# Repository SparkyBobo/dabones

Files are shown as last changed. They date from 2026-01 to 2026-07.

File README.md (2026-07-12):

# DaBones

DaBones is a Halloween animatronic rock show project combining mechanical characters, embedded electronics, lighting control, audio playback, and stage effects.

The goal is to create a repeatable live Halloween performance experience where animated characters perform as a band with synchronized movement, lighting, and effects.

## Project Status

Current release:

**DaBones v1.0 — Halloween 2026**

The focus of v1.0 is a complete, reliable show experience.

The goal is not to complete every possible feature. Future enhancements are intentionally deferred into later releases.

## System Overview

DaBones consists of several integrated systems:

* Animated characters
* Mechanical motion systems
* Embedded controllers
* Lighting and DMX control
* Audio and MIDI synchronization
* Stage infrastructure
* Special effects

## Engineering Approach

The project follows a release-based engineering model:

* Define the release before building
* Capture design decisions and tradeoffs
* Separate ideas from commitments
* Document why decisions are made
* Build platforms that support future expansion

## Repository Contents

```
docs/
    Release definitions
    Architecture documentation
    Inventory
    Decisions
    Field notes

hardware/
    Electronics designs
    Mechanical designs
    Related hardware files

firmware/
    Embedded software
```

## Relationship to Portfolio

DaBones is one project within a larger personal engineering portfolio.

The portfolio repository contains cross-project planning, engineering practices, and field notes.

## Current Goal

Deliver a complete Halloween 2026 show with a defined minimum viable feature set and a reliable operating experience.

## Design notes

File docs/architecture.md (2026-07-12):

# DaBones System Architecture

## Purpose

This document describes the overall system architecture of DaBones.

It captures the relationships between subsystems and the design intent behind the show platform.

## System Overview

DaBones is an integrated embedded control and performance system.

Major subsystems include:

* Show control
* Character animation
* Lighting
* Audio synchronization
* Mechanical systems
* Stage infrastructure
* Effects

## Show Control

The show requires coordination between:

* Music playback
* Character actions
* Lighting events
* Special effects

The exact implementation will continue to evolve as the system matures.

## Character Systems

Each character consists of:

* Mechanical structure
* Motion mechanisms
* Electronics
* Embedded control
* Lighting elements where appropriate

Characters currently include:

* Joey
* Slash
* Beats
* Tickles
* Lizzy
* Witches

## Lighting System

The lighting system includes:

* DMX-controlled fixtures
* Custom DMX hardware
* Lighting grid/truss structure
* Playback/control software

The lighting platform is largely functional and will be integrated into the v1.0 show.

## Electronics Platform

Character electronics will use reusable controller designs where possible.

Shared hardware and firmware platforms reduce duplication and improve maintainability.

## Audio / MIDI

The show includes audio playback and MIDI-based synchronization.

The MIDI controller system is part of the show control architecture.

## Mechanical Systems

Mechanical design includes:

* Character frames
* Motion mechanisms
* Mounting systems
* Stage structures

Mechanical reliability is a primary release constraint.

## Design Principles

* Prefer reusable platforms
* Capture decisions
* Separate experiments from releases
* Build reliable systems before adding features

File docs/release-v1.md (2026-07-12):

# DaBones v1.0 Release Definition

## Purpose

DaBones v1.0 is the first complete Halloween show release.

The objective is a reliable, entertaining animatronic rock performance that can be presented to an audience.

## Deadline

Halloween 2026

## Release Philosophy

v1.0 prioritizes:

* A complete experience
* Reliability
* Integration
* Audience impact

Features that are interesting but not required for the core experience are deferred.

## Minimum Show

The v1.0 show should include:

* Completed stage environment
* Functional lighting system
* Music playback
* Animated performers
* Synchronized character actions
* Reliable show operation

## Primary Characters

Target v1.0 performers:

* Joey — lead singer
* Slash — guitar player
* Beats — drummer
* Supporting stage elements as schedule allows

## Infrastructure

Required:

* Stage
* Lighting grid/truss
* DMX control
* Power distribution
* Audio system

## Deferred Features

Potential future releases:

* Video system
* Additional characters
* Advanced effects
* Additional choreography
* Expanded automation

## Definition of Done

DaBones v1.0 is complete when:

* The show can run from start to finish
* The audience experience is complete
* Systems are reliable enough for repeated operation
* Remaining ideas can safely move to future releases

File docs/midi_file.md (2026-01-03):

# MIDI Files

## Overview

The DaBones use MIDI format 1 with multiple tracks, one for each "instrument", i.e., character or song element.
A file may contain all song elements or a single element. The file can be transferred to a song element and played
back upon request.

The advantage of using MIDI files is that the song elements can anticipate events from the file, giving
song elements a more natural representation of the event, i.e., the swing of the drum stick appears
more human and less mechanical. Files are used for final playback during a song.

## File Name

DaBones MIDI file names are standardized to provide organized but human readable names making it easy
to load a file and understand what it contains from the file name.

File names start with the unique sequence number for the song followed by an underscore. For example,
song `00 06` would start with "0006_". This makes it easy for the sequence to load the file for a given
song by searching the file list of a song number.

Additionally, files can be transferred between song elements using MIDI system exclusive events. The common
use case is to load the master song file to all elements from a controller. For details regarding file transfers, see [MIDI File Transfers](./midi_file_transfer.md).

## Header

Format 1 header chunk:

Bytes|Value
-----|-----
4D 54 68 64|MThd
00 00 00 06|chunk length
00 01	   |format 1
00 04	   |number tracks
00 60	   |division, 96 ticks per quarter note

### Division

The third word, division, specifies the meaning of the delta-times. It uses ticks per quarter-note:

bit 15|bits 14 thru 0
-----|-----
0|ticks per quarter-note

ticks per quarter-note represent the number of delta time "ticks" which make up a quarter-note.
For instance, if division is 96, then a time interval of an eighth-note between two events in the file would be 48.

## Track 0: Metadata

Track 0 contains the metadata for the file as a track chunk:

Bytes|Value
-----|-----
4D 54 72 6B|MTrk
00 00 xx xx|chunk length

Delta-Time|Event|Comments
-----|-----|-----
00|FF 00 02 xx xx|sequence number
00|FF 03 xx xx xx|sequence name
00|FF 04 04 6d 65 74 61|instrument name, "meta" for track 0
00|FF 20 01 00|MIDI channel prefix, 00000000 for track 0
00|FF 51 03 07 A1 20|tempo
00|FF 2F 00|end of track

### FF 00 02: sequence number

A unique sequence number for the song, e.g., `00 01`

### FF 03 len text: sequence name

The name of the sequence, e.g., 'Skeleton Sam'

### FF 04 len text: instrument name

A description of the type of instrumentation to be used in that track, e.g., "meta" for track 0. Informational only.

### FF 20 01 cc MIDI channel prefix

The MIDI channel for the track, e.g., 00000000 for track 0.

For a list of MIDI channels, see [MIDI Channels](./midi_channel.md)

### FF 51 03 tttttt: tempo

The song tempo in microseconds per MIDI quarter-note, e.g., 07 A1 20 = 500,000 usec/quarter note = 120 beats/minute.

### FF 2F 00 End of Track

This event is not optional. It is included so that an exact ending point may be specified for the track, so that an exact length is defined, which is necessary for tracks which are looped or concatenated.

## Track 1-n: Song element

Tracks 1-n are the different song elements. They are composed of events to trigger each element to correspond to the
sequence being played, e.g., vocal events for a singer:

Bytes|Value
-----|-----
4D 54 72 6B|MTrk
00 00 xx xx|chunk length

Delta-Time|Event|Comments
-----|-----|-----
00|FF 04 04 6d 65 74 61|instrument name, e.g., "joey" or "lights"
00|FF 20 01 cc|MIDI channel prefix.
xx|xx xx xx|MIDI events, i.e., triggers
00|FF 2F 00|end of track

### FF 04 len text: instrument name

A description of the song element for the track, e.g., "joey" or "lights". Informational only.

### FF 20 01 cc MIDI channel prefix

The MIDI channel for the track. This value, not the name, is used to determine which track
applies to which song element.

For a list of MIDI channels, see [MIDI Channels](./midi_channel.md)

### MIDI events

For a list of MIDI events such as notes, controls, and programs, see [MIDI Notes, Controls, and Programs](./midi_notes.md)

### FF 2F 00 End of Track
This event is not optional. It is included so that an exact ending point may be specified for the track, so that an exact length is defined, which is necessary for tracks which are looped or concatenated.

## Example File

The following is a sequence of bytes that represent a song with a male singer and electric guitar playing
at 96 ticks per quarter note, 4/4 time; 24 MIDI clocks/click, 8 32nd notes/24 MIDI clocks, 500,000 usec/quarter note = 120 beats/minute which plays for 4 beats.

Bytes|Value
-----|-----
4D 54 68 64|MThd
00 00 00 06|chunk length
00 01	   |format 1
00 03	   |3 tracks
00 60	   |division, 96 ticks per quarter note
4D 54 72 6B|MTrk, track 0
00 00 00 10|track length (16)
00 FF 00 02 00 00|sequence number, 0.
00 FF 03 74 65 73 74|sequence name, "test"
00 FF 04 04 6d 65 74 61|instrument name, "meta" for track 0
00 FF 20 01 00|MIDI channel prefix, 00 for track 0
00 FF 58 04 04 02 18 08|time signature
00 FF 51 03 07 A1 20|tempo
00 FF 2F 00|end of track
4D 54 72 6B|MTrk, track 1
00 00 00 10|chunk length (16)
00 FF 04 04 6a 6f 65 79|instrument name, "joey"
00 FF 20 01 01|MIDI channel prefix, 00000001 for male singer.
00 C0 05|??
81 40 90 4C 20|??
81 40 4C 00|Running status: note on, vel=0
00 FF 2F 00|end of track
4D 54 72 6B|MTrk, track 2
00 00 00 10|chunk length (16)
00 FF 04 04 73 6c 61 73 68|instrument name, "slash"
00 FF 20 01 06|MIDI channel prefix, 06 for electric guitar.
00 C0 05|??
81 40 90 4C 20|??
81 40 4C 00|Running status: note on, vel=0
00 FF 2F 00|end of track

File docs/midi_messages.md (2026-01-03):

# MIDI Messages

## Overview

The DaBones use MIDI messages, with one MIDI channel for each "instrument", i.e., character or song element.
The messages can be played live as you would play any other instrument to control the song elements.

The disadvantage of using MIDI messages is that song elements cannot anticipate messages, giving them
a less natural representation of the event, i.e., the swing of the drum stick appears
less human and more mechanical. Messages are not used for final playback during a show. Instead,
messages are used to synchronize the show elements during the show.

However, messages are useful during the programming stage. Each song element can respond to the messages
to help show where each song element will be for every moment in the song. While the mechanics may be
unnatural, this is acceptable during programming where it's more important to define the states than
the process of achieving the state.

## Song Playback

When used with MIDI files, MIDI messages can signal start, stop, and timing information for a song.
These messages include:

Status|Data Byte(s)|Description
------|------------|-----------
11110010|0lllllll 0mmmmmmm|Song Position Pointer. This is an internal 14 bit register that holds the number of MIDI beats (1 beat= six MIDI clocks) since the start of the song. l is the LSB, m the MSB.
11110011|0sssssss|Song Select. The Song Select specifies which sequence or song is to be played.
11110110||Tune Request. Upon receiving a Tune Request, all analog synthesisers should tune their oscillators.
11111000||Timing Clock. Sent 24 times per quarter note when synchronisation is required.
11111010||Start. Start the current sequence playing. (This message will be followed with Timing Clocks).
11111011||Continue. Continue at the point the sequence was Stopped.
11111100||Stop. Stop the current sequence.
11111110||Active Sensing. Use of this message is required. When initially sent, the receiver will expect to receive another Active Sensing message each 300ms (max), or it will assume that the connection has been terminated. At termination, the receiver will turn off all voices and return to normal (non-active sensing) operation.
11111111||Reset. Reset all receivers in the system to power-up status.
11110000||System Exclusive. System exclusive messages are used to transfer MIDI files between song elements and select files for playback. For details regarding file transfers, see [MIDI File Transfers](./midi_file_transfer.md).

For details regarding playback, see [MIDI Playback](./midi_playback.md).

## Song Element Control

MIDI messages, with one MIDI channel for each "instrument", i.e., character or song element, the messages can be played live as you would play any other instrument to control the song elements.
Much like a live MIDI stream might be used to control instruments. In this mode, each song element will
respond to its MIDI channel and messages the same as it would during playback, except the element is not
able to anticipate the next event, e.g., the swing of the drum stick appears more mechanical and less human.

Status|Data Byte(s)|Description
------|------------|-----------
1000nnnn|0kkkkkkk 0vvvvvvv|Note Off event. This message is sent when a note is released (ended). (kkkkkkk) is the key (note) number. (vvvvvvv) is the velocity.
1001nnnn|0kkkkkkk 0vvvvvvv|Note On event. This message is sent when a note is depressed (start). (kkkkkkk) is the key (note) number. (vvvvvvv) is the velocity.
1011nnnn|0ccccccc 0vvvvvvv|Control Change. This message is sent when a controller value changes. Controllers include devices such as pedals and levers. Certain controller numbers are reserved for specific purposes. See Channel Mode Messages. (ccccccc) is the controller number. (vvvvvvv) is the new value.
1100nnnn|0ppppppp|Program Change. This message sent when the patch number changes. (ppppppp) is the new program number.
1110nnnn|0lllllll 0mmmmmmm|Pitch Wheel Change. This message is sent to indicate a change in the pitch wheel. The pitch wheel is measured by a fourteen bit value. Centre (no pitch change) is 2000H. Sensitivity is a function of the transmitter. (lllllll) are the least significant 7 bits. (mmmmmmm) are the most significant 7 bits.

For a list of MIDI channels, see [MIDI Channels](./midi_channel.md)
For a list of MIDI notes, controls, and programs, see [MIDI Notes, Controls, and Programs](./midi_notes.md)

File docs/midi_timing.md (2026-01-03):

# MIDI Playback Timing

## Overview

The DaBones use a combination of System Common and System Real-Time messages with MIDI channel 0 for
playback of locally stored MIDI files. The timing related messages and file sections include:

## Messages

Status|Data Byte(s)|Description
------|------------|-----------
11110010|0lllllll 0mmmmmmm|Song Position Pointer. This is an internal 14-bit register that holds the number of MIDI beats (1 beat = six MIDI clocks) since the start of the song. l is the LSB, m the MSB.
11111000||Timing Clock. Sent 24 times per quarter note when synchronisation is required.
11111010||Start. Start the current sequence playing. (This message will be followed with Timing Clocks).

### Song Position Pointer.

This is an internal 14-bit register that holds the number of MIDI beats (1 beat = six MIDI clocks) since the start of the song. l is the LSB, m the MSB: 0lllllll 0mmmmmmm.

The controller may use this message to set the song element sequencers to a fixed point in the song. This register
is reset to 0 when a new song is played.

### Timing Clock

Sent 24 times per quarter note for real-time playback. Can be sent at a slower rate to step through the
events in the MIDI file.

### Start

Start the current sequence playing. (This message will be followed with Timing Clocks). This will reset the song
position register to 0.

## Files

File section|Value|Comment
------------|-----|-----------
Header|division|ticks per quarter-note
Track 0|time signature|time signature
Track 0|tempo|microseconds per MIDI quarter-note

### Division

The division specifies the meaning of the delta-times. It uses ticks per quarter-note:

bit 15|bits 14 thru 0
-----|-----
0|ticks per quarter-note

ticks per quarter-note represent the number of delta time "ticks" which make up a quarter-note.
For instance, if division is 96, then a time interval of an eighth-note between two events in the file would be 48.
If not supplied, the default value is 24.

### Tempo

The song tempo in microseconds per MIDI quarter-note, e.g., 07 A1 20 = 500,000 usec/quarter note = 120 beats/minute.

## Calculations

When playing MIDI files locally, the following process describes how timing is controlled.

1. When a file is loaded, the ticks per quarter note, division, and tempo are set based on the contents of the file header and track metadata. Changes to these parameters are not supported. The position is reset to 0.
2. Determine the ticks per timing clock: ticks per timing clock = division / 24. Default is 1.
3. Calculate the expected timing clock interval: timing clock interval = tempo / 24 milliseconds.
4. Calculate the tick rate: ticks per millisecond = ticks per timing clock / timing clock interval.
5. If no timing clocks are received, play using these calculated variables.
6. If timing clocks are received, use them to override the expected timing and recalculate the tick rate.
7. Recalculate the tick rate using actual timing clock intervals: ticks per millisecond = ticks per timing clock / (current clock time - previous clock time).
8. Increment ticks using the last known tick rate. Timing may be inaccurate if intervals change.
9. Evaluate file events for every tick increment.
10. Increment the song position pointer by 1 every 6 MIDI timing clocks.
11. If the song position pointer is adjusted, calculate ticks = song position pointer * ticks per timing clock * 6 and pause playback.

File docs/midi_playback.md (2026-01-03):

# MIDI Playback

## Overview

The DaBones use a combination of System Common and System Real-Time messages with MIDI channel 0 for
playback of locally stored MIDI files.

For details regarding files, see [MIDI Files](./midi_file.md).
For details regarding file transfers, see [MIDI File Transfers](./midi_file_transfer.md).

## Messages

When used with MIDI files, MIDI messages can signal start, stop, and timing information for a song.
These messages include:

Status|Data Byte(s)|Description
------|------------|-----------
11110010|0lllllll 0mmmmmmm|Song Position Pointer. This is an internal 14-bit register that holds the number of MIDI beats (1 beat = six MIDI clocks) since the start of the song. l is the LSB, m the MSB.
11110011|0sssssss|Song Select. The Song Select specifies which sequence or song is to be played.
11110110||Tune Request. Upon receiving a Tune Request, song elements should "tune" their instruments.
11111000||Timing Clock. Sent 24 times per quarter note when synchronisation is required.
11111010||Start. Start the current sequence playing. (This message will be followed with Timing Clocks).
11111011||Continue. Continue at the point the sequence was Stopped.
11111100||Stop. Stop the current sequence.
11111110||Active Sensing. Use of this message is required. When initially sent, the receiver will expect to receive another Active Sensing message each 300ms (max), or it will be assume that the connection has been terminated. At termination, the receiver will turn off all voices and return to normal (non-active sensing) operation.
11110000|01111111 01111111 00000004 00000001 vvvvvvvv vvvvvvvv|Master volume. Sets the master volume, (vvvvvvvv vvvvvvvv) is the volume level 0-65535, lsb first.
11110000|01111111 01111111 10111111 00000001 ...|Open File
11110000|01111111 01111111 10111111 00000004 ...|Close File
11111111||Reset. Reset all receivers in the system to power-up status.

### Song Position Pointer.

This is an internal 14-bit register that holds the number of MIDI beats (1 beat = six MIDI clocks) since the start of the song. l is the LSB, m the MSB: 0lllllll 0mmmmmmm.

The controller may use this message to set the song element sequencers to a fixed point in the song. This register
is reset to 0 when a new song is played.

### Song Select

The song Select specifies which sequence or song is to be played. It only works for songs 0-127. For higher
song numbers use the system exclusive message Open File for file selection.

### Tune Request

Upon receiving a Tune Request, all song elements "tune" their instruments. This request will trigger the song element
to exercise its functionality in a "power up" sequence to visually show all elements working. The tune request
will last 10 seconds during which the song element will continue to display its pattern.

### Timing Clock

Sent 24 times per quarter note for real-time playback. Can be sent at a slower rate to step through the
events in the MIDI file.

### Start

Start the current song playing. (This message will be followed with Timing Clocks). This will reset the song
position register to 0.

### Continue

Continue at the point the sequence was Stopped. Operates like a pause button on a cassette deck.

### Stop

Stop the current sequence. This will not reset the song position register to 0.

### Active Sensing

Use of this message is required. When initially sent, the receiver will expect to receive another Active Sensing message each 300ms (max), or it will assume that the connection has been terminated. At termination, the receiver will turn off all voices and return to normal (non-active sensing) operation.

### Master Volume

Sets the master volume, (vvvvvvvv vvvvvvvv) is the volume level 0-65535, LSB first. This is a real-time universal system exclusive event and belongs to the playback category.

### Open File

This message specifies the type and location of a MIDI file so it can be loaded. It does not cause the
song to play. This can be used in place of Song Select messages which the song number exceeds 127 or
for specifying a non-standard file name. This is a non-real-time universal system exclusive event and belongs to the playback category.

The command includes the following data bytes:

Data|Comment
----|-------
0ccccccc 0ccccccc|Two 7-bit bytes for command context. Use 00000000 00000000.
0lllllll 0lllllll|Two 7-bit byte combined byte count of type and name, lsb first.
0ttttttt 0ttttttt 0ttttttt 0ttttttt|Four 7-bit bytes for type. Use 'MIDI'.
0nnnnnnn ...|Variable-length, null-terminated, 7-bit ASCII byte file name. Maximum length including terminator is 261 bytes.

If the name specified is a partial match for a single file, that file is opened. For instance, if the
file name is "0006_" and a single file such as "0006_ome_text.mid" exists, it is opened.

### Close File

This message closes an open file and deallocates any memory allocated for the file's contents. This is a non-real-time universal system exclusive event and belongs to the playback category.

The command includes the following data bytes:

Data|Comment
----|-------
0ccccccc 0ccccccc|Two 7-bit bytes for command context. Use 00000000 00000000.

### Reset

Reset all receivers in the system to power-up status. Upon reset, all song elements will perform a "tune" operation
as described in Tune Request.

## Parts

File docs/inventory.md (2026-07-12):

# DaBones Inventory

This document tracks existing hardware, completed work, prototypes, and remaining development.

Status categories:

* Complete
* Functional prototype
* In progress
* Needs design
* Needs build
* Needs integration

---

# Lighting System

Status: Mostly functional

Completed:

* Lighting purchased
* Power wiring built
* DMX wiring built
* DMX circuit built and tested
* Lighting grid/truss operational

Needs:

* Truss reinforcement
* Control software
* Playback software

---

# Slash

Status: Mechanical prototype complete

Completed:

* Guitar mechanics
* Stage mounting
* Skeleton mounting

Needs:

* Circuit build
* Programming
* Costume decoration

---

# Beats

Status: Partial build

Completed:

* Stage
* Partial drum kit
* Parts acquired
* Bass mounted
* High hat mounted
* Initial controller board design exists

Needs:

* Electronics assembly
* Firmware
* Drum mechanism design
* Tom and snare mounting

---

# Tickles

Status: Partial build

Completed:

* Stage
* Keyboard mounted
* Skeleton mounted
* Skulls completed
* Mouth movement working

Needs:

* Playing mechanism
* Spine/skull attachment

---

# Joey

Status: Advanced prototype

Completed:

* Foot tap
* Head movement
* Head mounting
* Body frame
* Hip swing/pelvis mechanism

Needs:

* Body attachment redesign
* Accelerometer integration
* Electronics
* Firmware

---

# Lizzy

Status: Partial build

Completed:

* Head assembly
* Sound
* Mouth movement
* Stage

Needs:

* Body mounting
* Arm mechanism design

---

# Witches

Status: Partial build

Completed:

* Heads prepared
* Mouth mechanisms planned
* Neck motors available

Needs:

* Stage attachment
* Motor installation
* Electronics

---

# Effects

## Smoke

Status: Prototype

Completed:

* Coffee machine prototype
* Fan box
* Fan and tubing

Needs:

* Better enclosure
* Drum riser integration
* Tubing/grille work

## Strobe

Status:
Functional

## Mirror Ball

Status:
Partial

Needs:

* Motor mounting
* Hanging system
* Driver wiring

---

# Marshall Stacks

Status:
Designed / parts available

Completed:

* Design
* Speakers
* Power distribution components
* Control strip components

Needs:

* Construction
* Assembly

---

# Video

Status:
Partial prototype

Completed:

* Approximately half constructed
* Parts available

Needs:

* Testing
* Software

May be deferred from v1.0.

---

# MIDI Controller

Status:
Hardware complete

Needs:

* Programming

---

# Open Questions

* Final v1.0 character lineup
* Final show sequence
* Controller architecture
* Software architecture
* Deferred features

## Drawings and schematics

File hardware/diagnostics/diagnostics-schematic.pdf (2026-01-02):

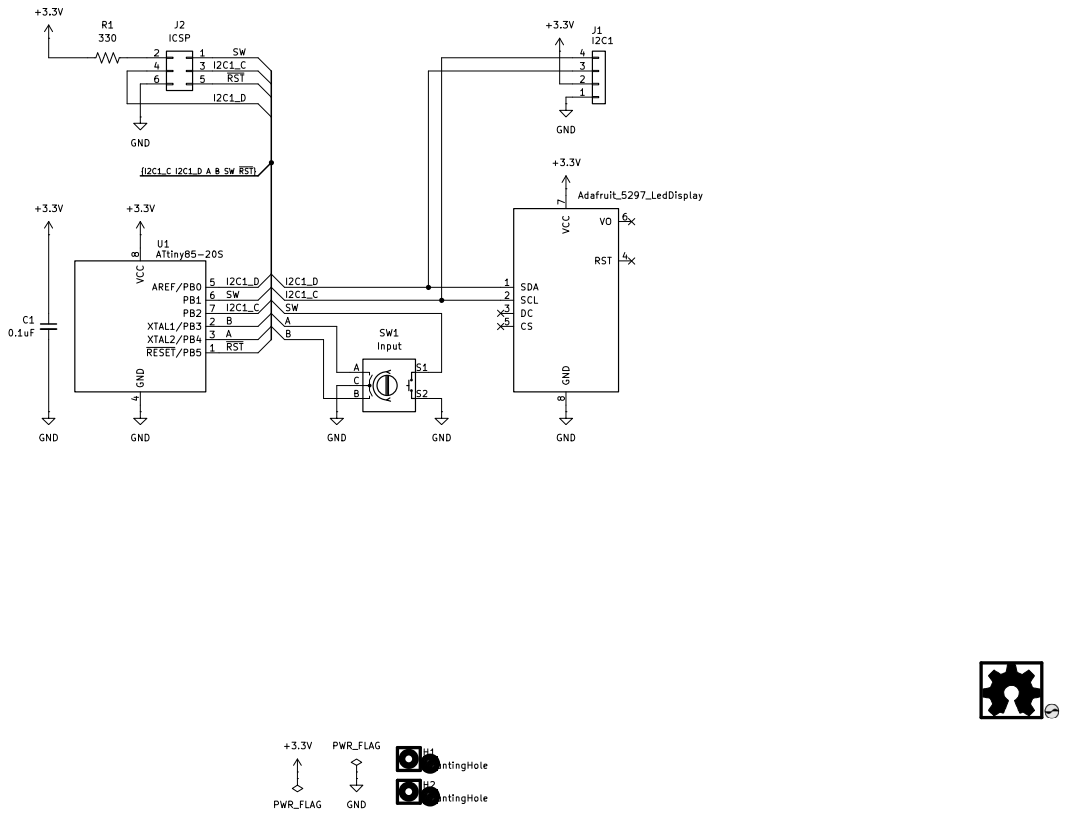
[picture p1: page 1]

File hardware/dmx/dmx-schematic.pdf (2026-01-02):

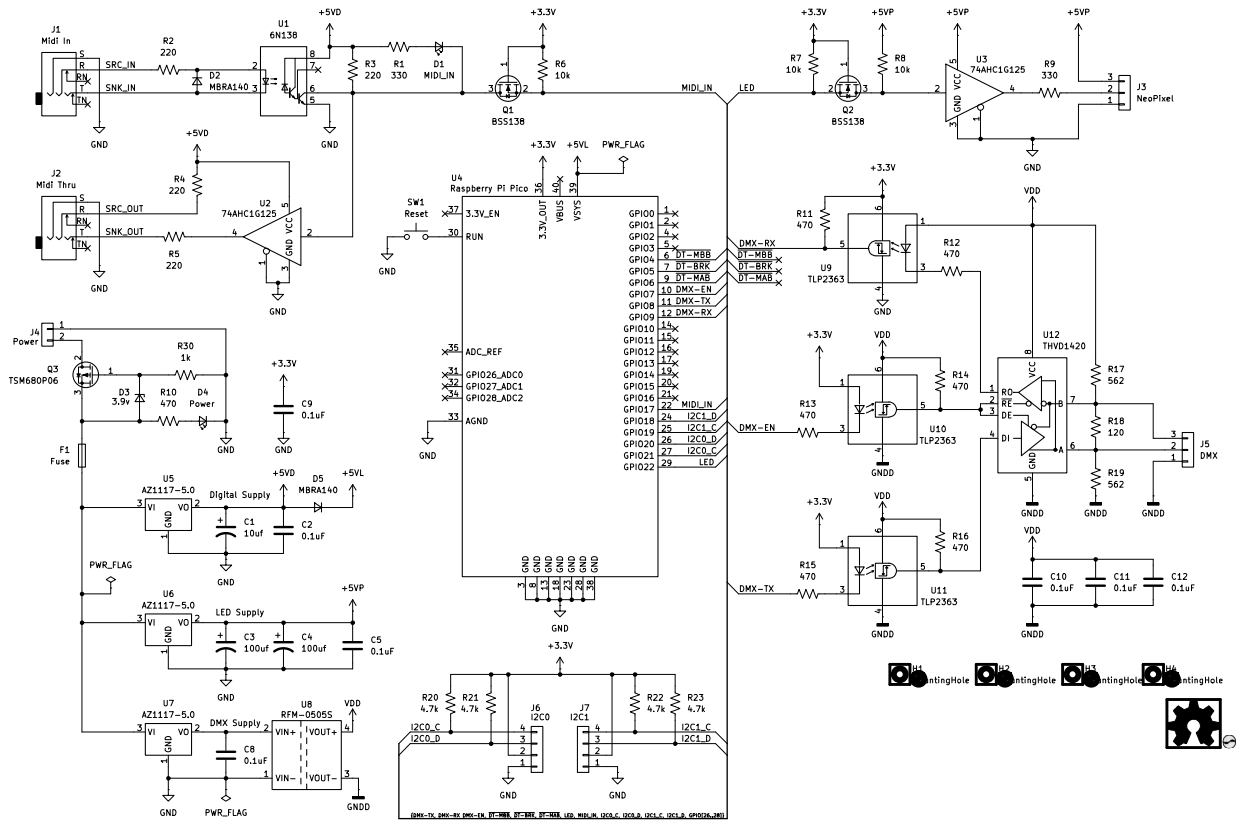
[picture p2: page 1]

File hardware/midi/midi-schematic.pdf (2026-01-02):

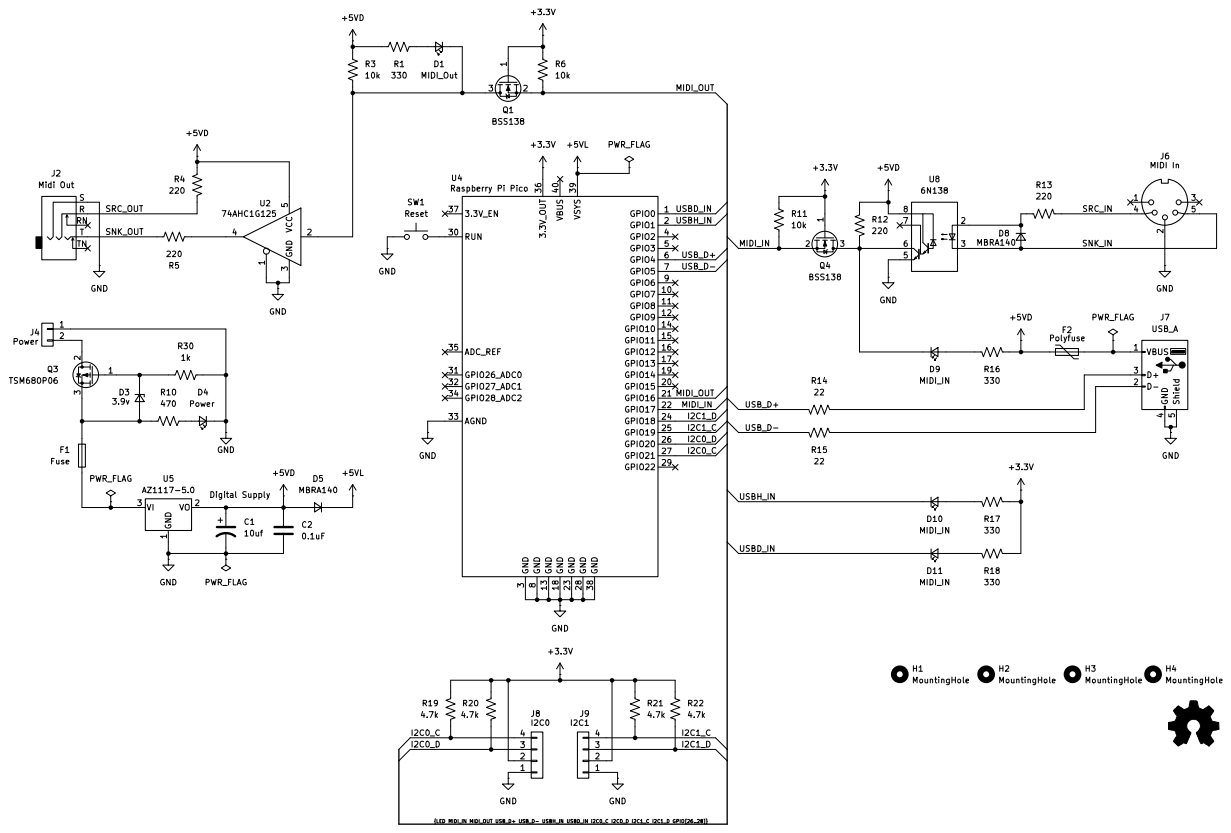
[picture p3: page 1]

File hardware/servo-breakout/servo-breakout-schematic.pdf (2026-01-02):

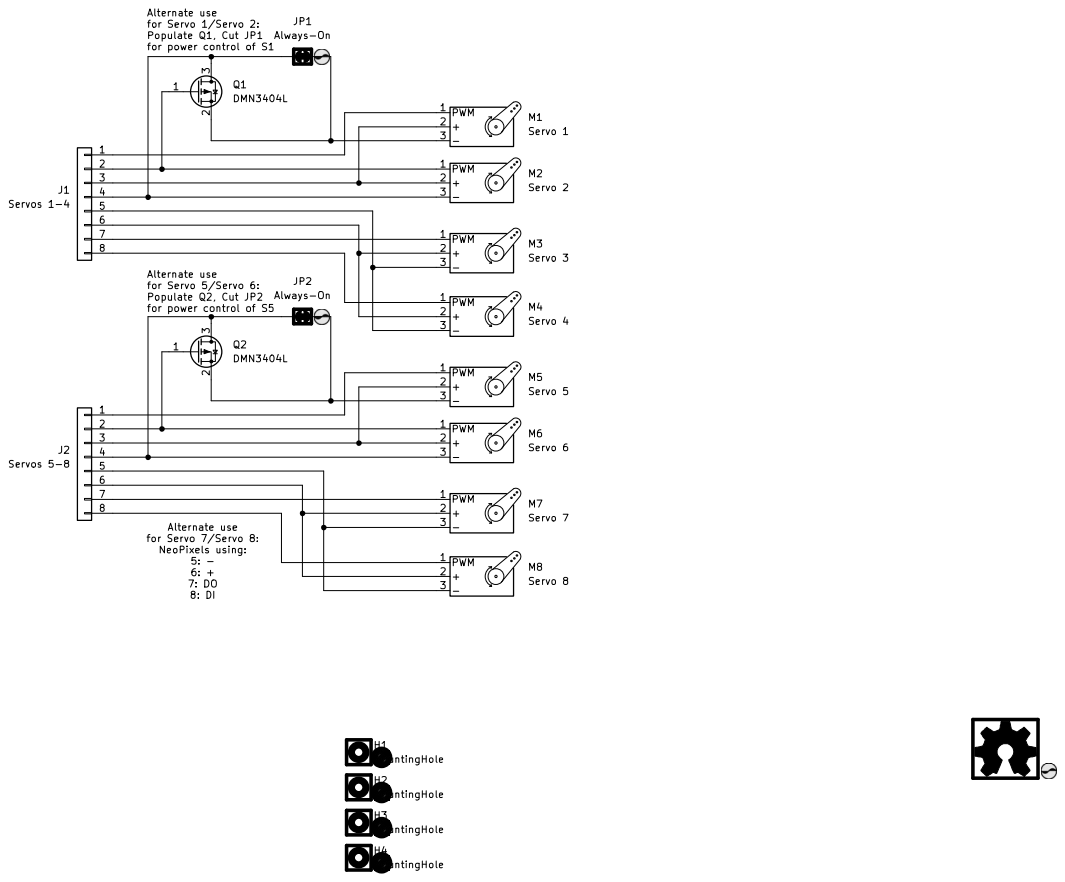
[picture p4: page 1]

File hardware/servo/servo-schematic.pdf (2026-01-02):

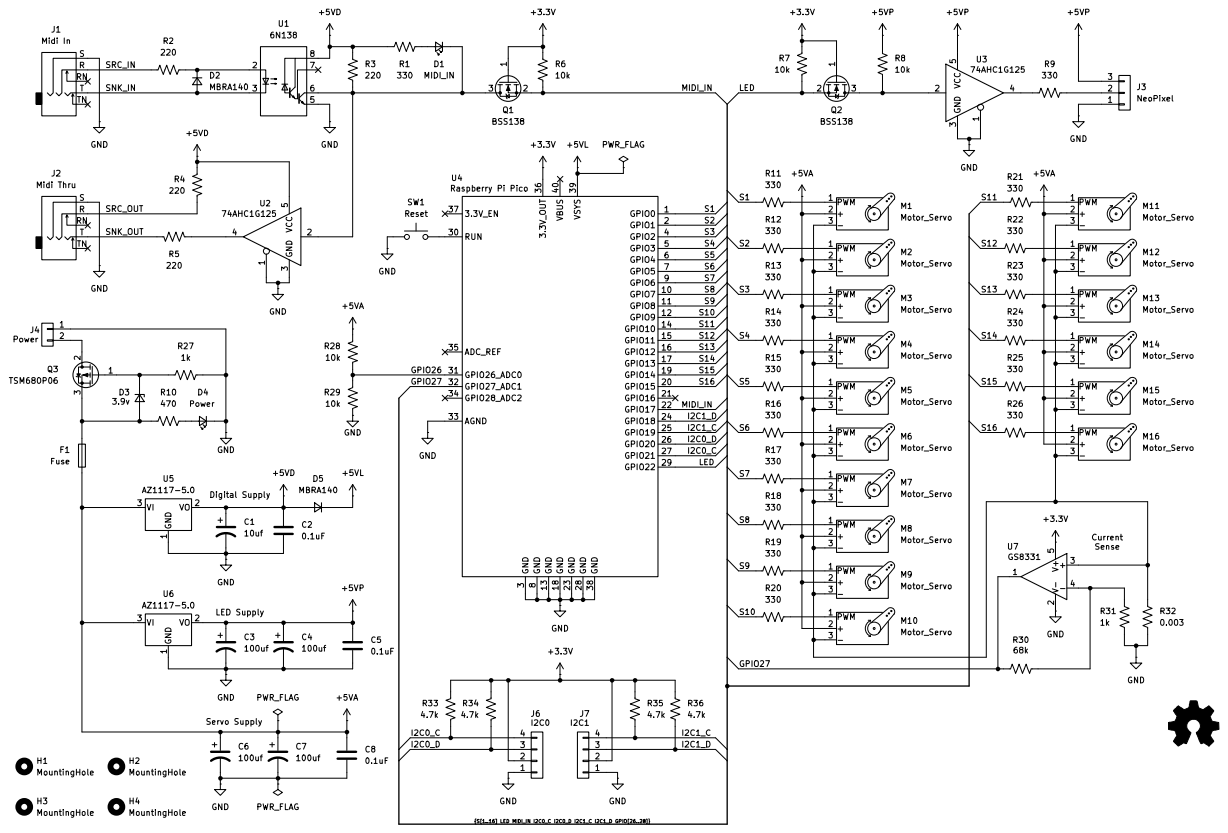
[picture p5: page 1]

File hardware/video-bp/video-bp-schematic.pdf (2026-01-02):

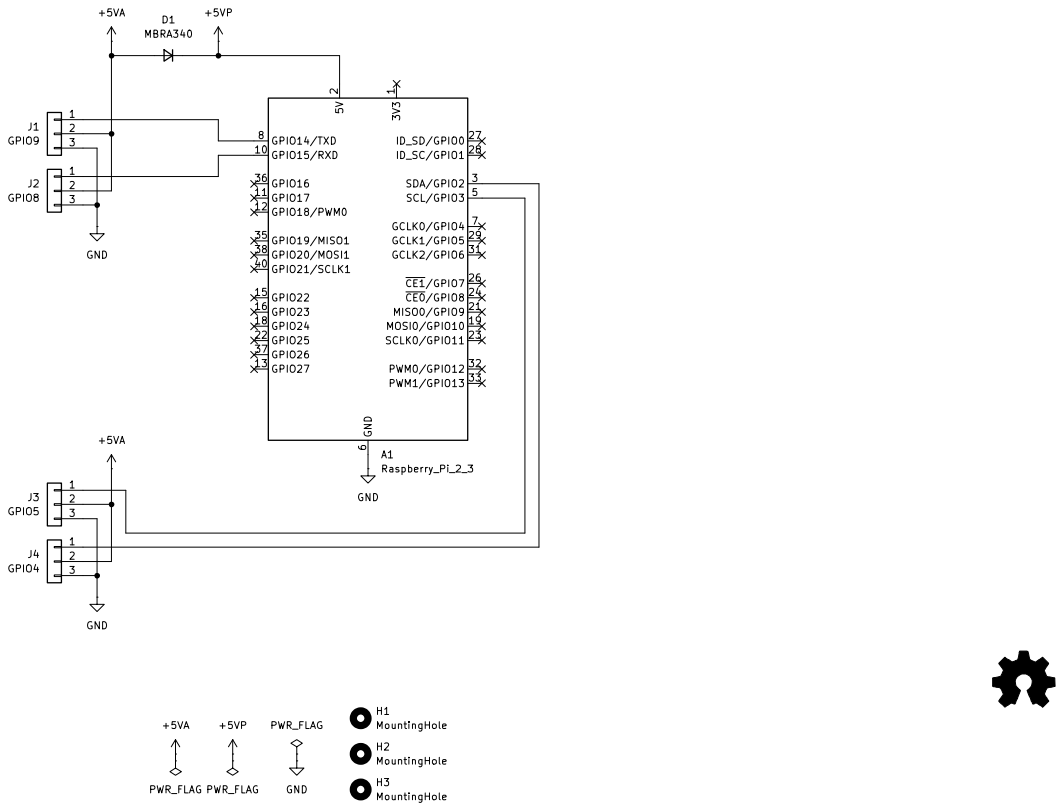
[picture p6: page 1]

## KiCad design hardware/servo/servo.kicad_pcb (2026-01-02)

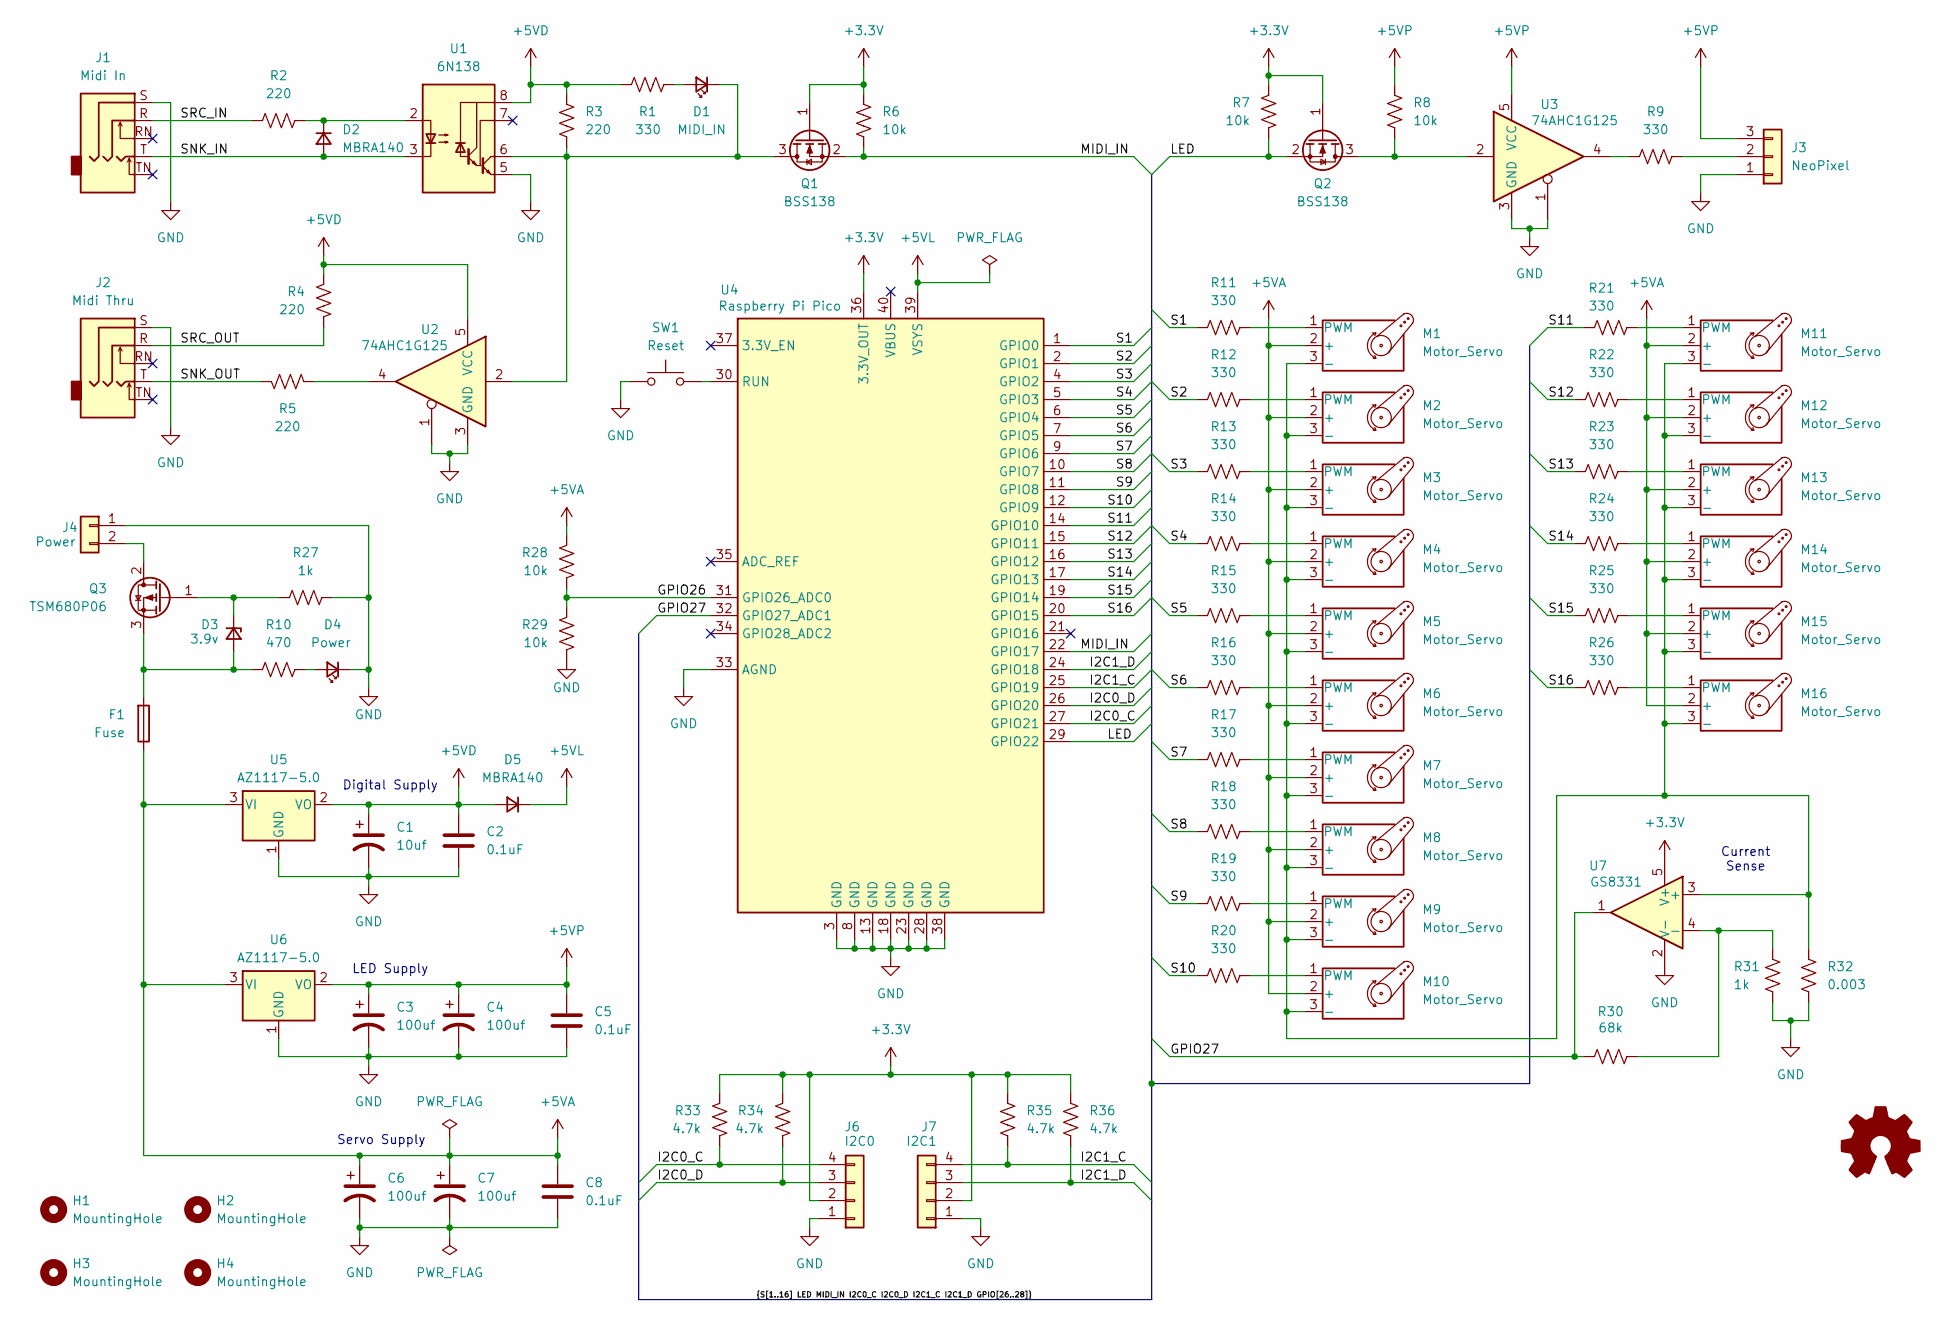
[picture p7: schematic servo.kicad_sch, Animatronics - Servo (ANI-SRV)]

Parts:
C1: 10uf; CP_Radial_D5.0mm_P2.00mm
C2, C5, C8: 0.1uF; C_Rect_L4.0mm_W2.5mm_P2.50mm
C3, C4, C6, C7: 100uf; CP_Radial_D5.0mm_P2.00mm
D1: MIDI_IN; LED_1206_3216Metric_Pad1.42x1.75mm_HandSolder
D2, D5: MBRA140; D_SMA_Handsoldering
D3: 3.9v; D_SOD-123
D4: Power; LED_1206_3216Metric_Pad1.42x1.75mm_HandSolder
F1: Fuse; atc_fuse_vertical
H1, H2, H3, H4: MountingHole; MountingHole_3.2mm_M3
J1: Midi In; Jack_3.5mm_Adafruit_1699_Horizontal
J2: Midi Thru; Jack_3.5mm_Adafruit_1699_Horizontal
J3: NeoPixel; PhoenixContact_MC_1,5_3-G-3.81_1x03_P3.81mm_Horizontal
J4: Power; PhoenixContact_MC_1,5_2-G-3.81_1x02_P3.81mm_Horizontal
J6: I2C0; JST_SH_BM04B-SRSS-TB_1x04-1MP_P1.00mm_Vertical
J7: I2C1; JST_SH_SM04B-SRSS-TB_1x04-1MP_P1.00mm_Horizontal
M1, M2, M3, M4, M5, M6, M7, M8, M9, M10, M11, M12, M13, M14, M15, M16: Motor_Servo; PinHeader_1x03_P2.54mm_Vertical
Q1, Q2: BSS138; SOT-23
Q3: TSM680P06; TO-252-2
R1, R9, R11, R12, R13, R14, R15, R16, R17, R18, R19, R20, R21, R22, R23, R24, R25, R26: 330; R_1206_3216Metric_Pad1.30x1.75mm_HandSolder
R2, R3, R4, R5: 220; R_1206_3216Metric_Pad1.30x1.75mm_HandSolder
R6, R7, R8, R28, R29: 10k; R_1206_3216Metric_Pad1.30x1.75mm_HandSolder
R10: 470; R_1206_3216Metric_Pad1.30x1.75mm_HandSolder
R27, R31: 1k; R_1206_3216Metric_Pad1.30x1.75mm_HandSolder
R30: 68k; R_1206_3216Metric_Pad1.30x1.75mm_HandSolder
R32: 0.003; R_1206_3216Metric_Pad1.30x1.75mm_HandSolder
R33, R34, R35, R36: 4.7k; R_1206_3216Metric_Pad1.30x1.75mm_HandSolder
SW1: Reset; SW_PUSH_6mm
U1: 6N138; SMDIP-8_W9.53mm
U2, U3: 74AHC1G125; SOT-23-5_HandSoldering
U4: Raspberry Pi Pico; RP_Pico_DIP
U5, U6: AZ1117-5.0; SOT-223-3_TabPin2
U7: GS8331; TSOT-23-5

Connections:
+3.3V: J6.2, J7.2, Q1.1 (G), Q2.1 (G), R6.2, R7.2, R33.2, R34.2, R35.2, R36.2, U4.36 (3.3V_OUT), U7.5 (V+)
+5VA: C6.1, C7.1, C8.1, F1.1, M1.2 (+), M2.2 (+), M3.2 (+), M4.2 (+), M5.2 (+), M6.2 (+), M7.2 (+), M8.2 (+), M9.2 (+), M10.2 (+), M11.2 (+), M12.2 (+), M13.2 (+), M14.2 (+), M15.2 (+), M16.2 (+), R28.2, U5.3 (VI), U6.3 (VI)
+5VD: C1.1, C2.1, D5.2 (A), R1.2, R3.1, R4.2, U1.8 (VCC), U2.5 (VCC), U5.2 (VO)
+5VL: D5.1 (K), U4.39 (VSYS)
+5VP: C3.1, C4.1, C5.1, J3.3, R8.2, U3.5 (VCC), U6.2 (VO)
/GPIO26: R28.1, R29.2, U4.31 (GPIO26_ADC0)
/GPIO27: R30.1, U4.32 (GPIO27_ADC1), U7.1
/I2C0_C: J6.4, R33.1, U4.27 (GPIO21)
/I2C0_D: J6.3, R34.1, U4.26 (GPIO20)
/I2C1_C: J7.4, R35.1, U4.25 (GPIO19)
/I2C1_D: J7.3, R36.1, U4.24 (GPIO18)
/LED: Q2.2 (S), R7.1, U4.29 (GPIO22)
/MIDI_IN: Q1.2 (S), R6.1, U4.22 (GPIO17)
/S1: R11.1, U4.1 (GPIO0)
/S2: R12.1, U4.2 (GPIO1)
/S3: R13.1, U4.4 (GPIO2)
/S4: R14.1, U4.5 (GPIO3)
/S5: R15.1, U4.6 (GPIO4)
/S6: R16.1, U4.7 (GPIO5)
/S7: R17.1, U4.9 (GPIO6)
/S8: R18.1, U4.10 (GPIO7)
/S9: R19.1, U4.11 (GPIO8)
/S10: R20.1, U4.12 (GPIO9)
/S11: R21.1, U4.14 (GPIO10)
/S12: R22.1, U4.15 (GPIO11)
/S13: R23.1, U4.16 (GPIO12)
/S14: R24.1, U4.17 (GPIO13)
/S15: R25.1, U4.19 (GPIO14)
/S16: R26.1, U4.20 (GPIO15)
/SNK_IN: D2.2 (A), J1.T, U1.3 (C2)
/SNK_OUT: J2.T, R5.1
/SRC_IN: J1.R, R2.1
/SRC_OUT: J2.R, R4.1
GND: C1.2, C2.2, C3.2, C4.2, C5.2, C6.2, C7.2, C8.2, D4.1 (K), J1.S, J2.S, J3.1, J4.1, J6.1, J7.1, R27.2, R29.1, R31.1, R32.1, SW1.1, U1.5 (GND), U2.1, U2.3 (GND), U3.1, U3.3 (GND), U4.3 (GND), U4.8 (GND), U4.13 (GND), U4.18 (GND), U4.23 (GND), U4.28 (GND), U4.33 (AGND), U4.38 (GND), U5.1 (GND), U6.1 (GND), U7.2 (V-)
unnamed: D1.2 (A), R1.1
unnamed: D1.1 (K), Q1.3 (D), R3.2, U1.6 (VO2), U2.2
unnamed: D2.1 (K), R2.2, U1.2 (C1)
unnamed: D3.2 (A), F1.2, Q3.3 (S), R10.1
unnamed: D3.1 (K), Q3.1 (G), R27.1
unnamed: D4.2 (A), R10.2
unnamed: J3.2, R9.2
unnamed: J4.2, Q3.2 (D)
unnamed: M1.3 (-), M2.3 (-), M3.3 (-), M4.3 (-), M5.3 (-), M6.3 (-), M7.3 (-), M8.3 (-), M9.3 (-), M10.3 (-), M11.3 (-), M12.3 (-), M13.3 (-), M14.3 (-), M15.3 (-), M16.3 (-), R32.2, U7.3 (+)
unnamed: M1.1 (PWM), R11.2
unnamed: M2.1 (PWM), R12.2
unnamed: M3.1 (PWM), R13.2
unnamed: M4.1 (PWM), R14.2
unnamed: M5.1 (PWM), R15.2
unnamed: M6.1 (PWM), R16.2
unnamed: M7.1 (PWM), R17.2
unnamed: M8.1 (PWM), R18.2
unnamed: M9.1 (PWM), R19.2
unnamed: M10.1 (PWM), R20.2
unnamed: M11.1 (PWM), R21.2
unnamed: M12.1 (PWM), R22.2
unnamed: M13.1 (PWM), R23.2
unnamed: M14.1 (PWM), R24.2
unnamed: M15.1 (PWM), R25.2
unnamed: M16.1 (PWM), R26.2
unnamed: Q2.3 (D), R8.1, U3.2
unnamed: R5.2, U2.4
unnamed: R9.1, U3.4
unnamed: SW1.2, U4.30 (RUN)
unnamed: R30.2, R31.2, U7.4 (-)

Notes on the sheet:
Current Sense
LED Supply
Digital Supply
Servo Supply

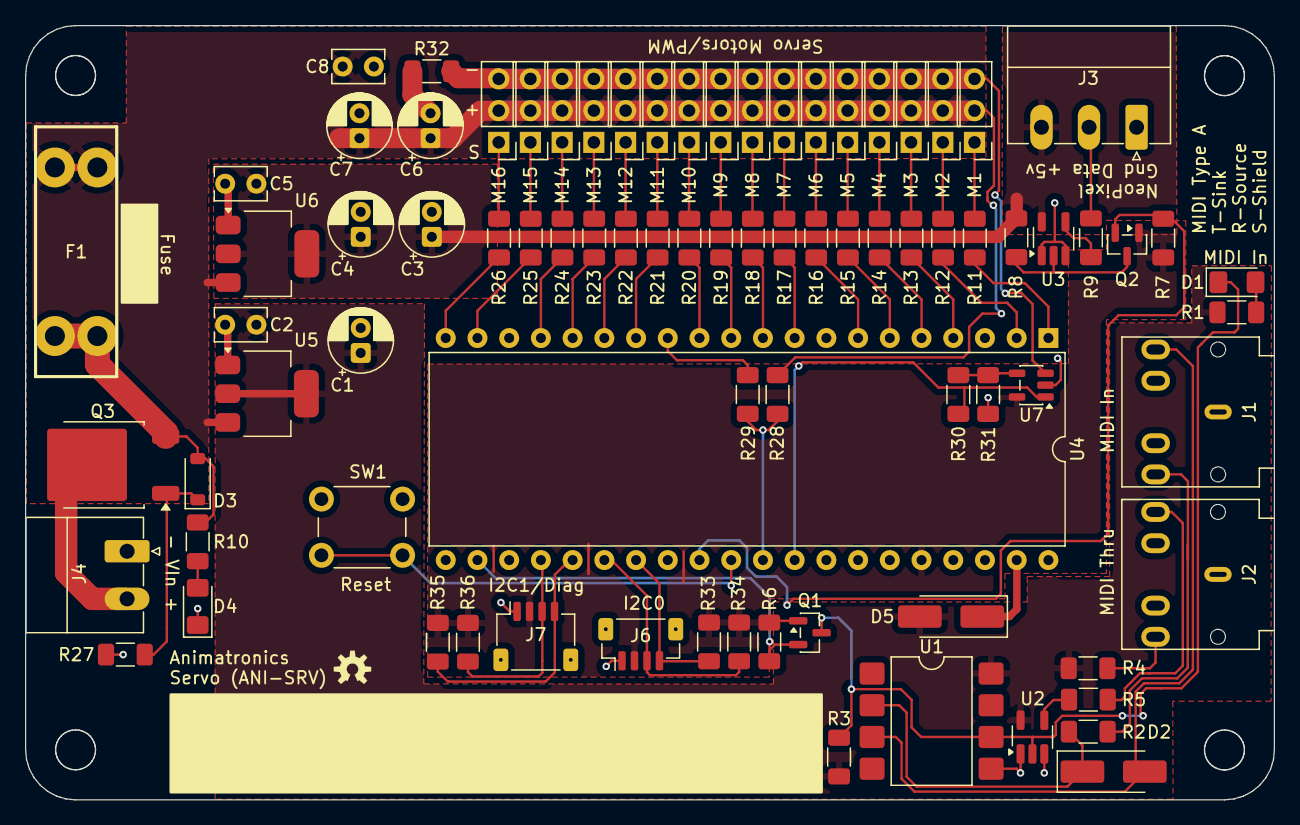
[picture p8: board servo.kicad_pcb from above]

Board: 2 copper layers, 100.0 x 62.0 mm, 87 parts (0 on the bottom side), 64 nets.

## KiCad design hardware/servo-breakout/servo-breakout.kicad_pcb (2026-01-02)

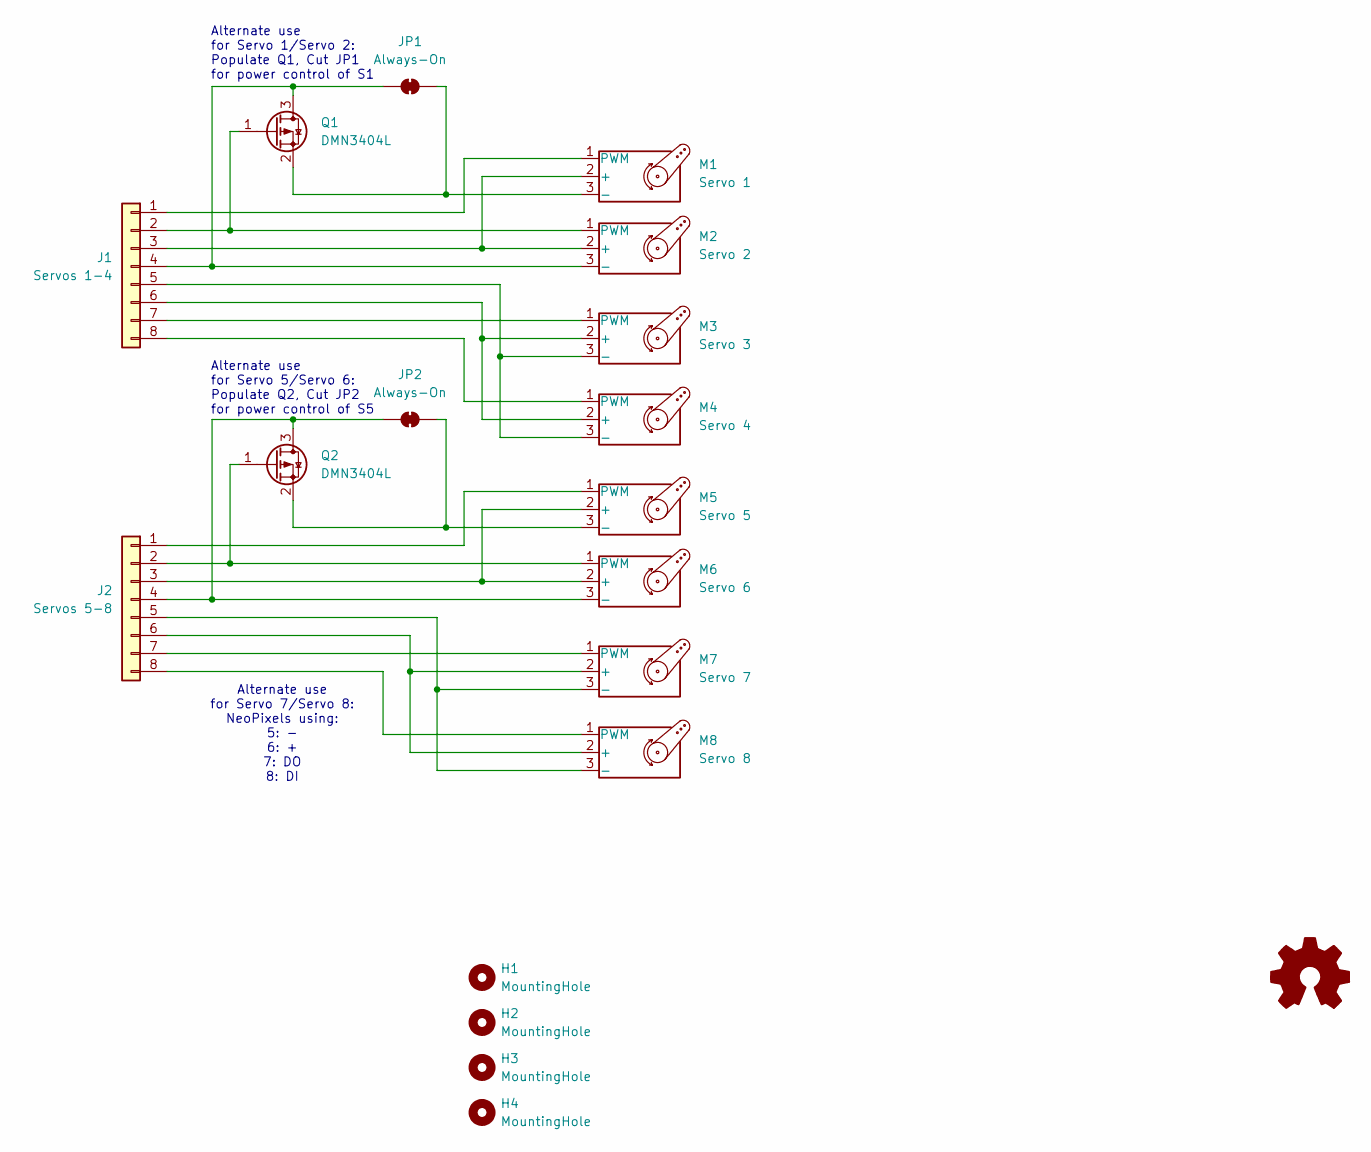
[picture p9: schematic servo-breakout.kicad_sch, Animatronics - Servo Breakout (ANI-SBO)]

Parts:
H1, H2, H3, H4: MountingHole; MountingHole_3.2mm_M3
J1: Servos 1-4; PhoenixContact_MCV_1,5_8-G-3.81_1x08_P3.81mm_Vertical
J2: Servos 5-8; PhoenixContact_MCV_1,5_8-G-3.81_1x08_P3.81mm_Vertical
JP1, JP2: Always-On; SolderJumper-2_P1.3mm_Bridged2Bar_RoundedPad1.0x1.5mm
M1: Servo 1; PinHeader_1x03_P2.54mm_Horizontal
M2: Servo 2; PinHeader_1x03_P2.54mm_Horizontal
M3: Servo 3; PinHeader_1x03_P2.54mm_Horizontal
M4: Servo 4; PinHeader_1x03_P2.54mm_Horizontal
M5: Servo 5; PinHeader_1x03_P2.54mm_Horizontal
M6: Servo 6; PinHeader_1x03_P2.54mm_Horizontal
M7: Servo 7; PinHeader_1x03_P2.54mm_Horizontal
M8: Servo 8; PinHeader_1x03_P2.54mm_Horizontal
Q1, Q2: DMN3404L; TSOT-23_HandSoldering

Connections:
unnamed: J1.1, M1.1 (PWM)
unnamed: J1.2, M2.1 (PWM), Q1.1 (G)
unnamed: J1.3, M1.2 (+), M2.2 (+)
unnamed: J1.4, JP1.2 (B), M2.3 (-), Q1.3 (D)
unnamed: J1.5, M3.3 (-), M4.3 (-)
unnamed: J1.6, M3.2 (+), M4.2 (+)
unnamed: J1.7, M3.1 (PWM)
unnamed: J1.8, M4.1 (PWM)
unnamed: J2.1, M5.1 (PWM)
unnamed: J2.2, M6.1 (PWM), Q2.1 (G)
unnamed: J2.3, M5.2 (+), M6.2 (+)
unnamed: J2.4, JP2.2 (B), M6.3 (-), Q2.3 (D)
unnamed: J2.5, M7.3 (-), M8.3 (-)
unnamed: J2.6, M7.2 (+), M8.2 (+)
unnamed: J2.7, M7.1 (PWM)
unnamed: J2.8, M8.1 (PWM)
unnamed: JP1.1 (A), M1.3 (-), Q1.2 (S)
unnamed: JP2.1 (A), M5.3 (-), Q2.2 (S)

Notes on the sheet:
Alternate use for Servo 7/Servo 8: NeoPixels using: 5: - 6: + 7: DO 8: DI
Alternate use for Servo 1/Servo 2: Populate Q1, Cut JP1 for power control of S1
Alternate use for Servo 5/Servo 6: Populate Q2, Cut JP2 for power control of S5

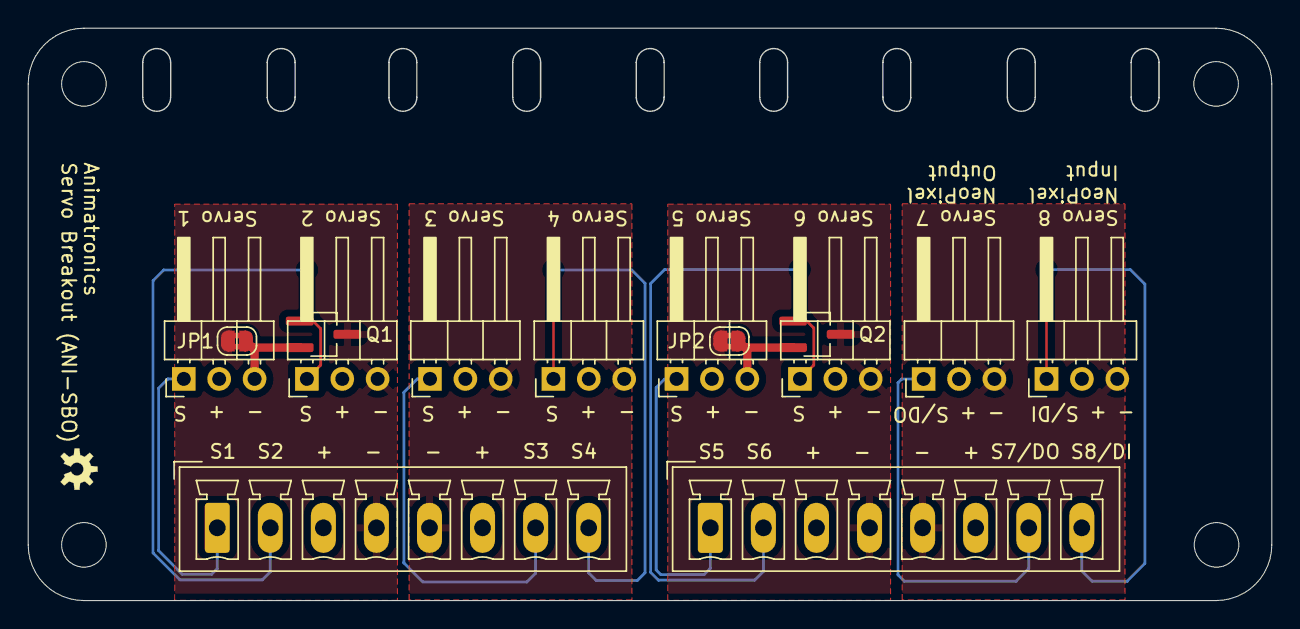
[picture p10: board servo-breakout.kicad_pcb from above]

Board: 2 copper layers, 89.3 x 41.1 mm, 18 parts (0 on the bottom side), 18 nets.

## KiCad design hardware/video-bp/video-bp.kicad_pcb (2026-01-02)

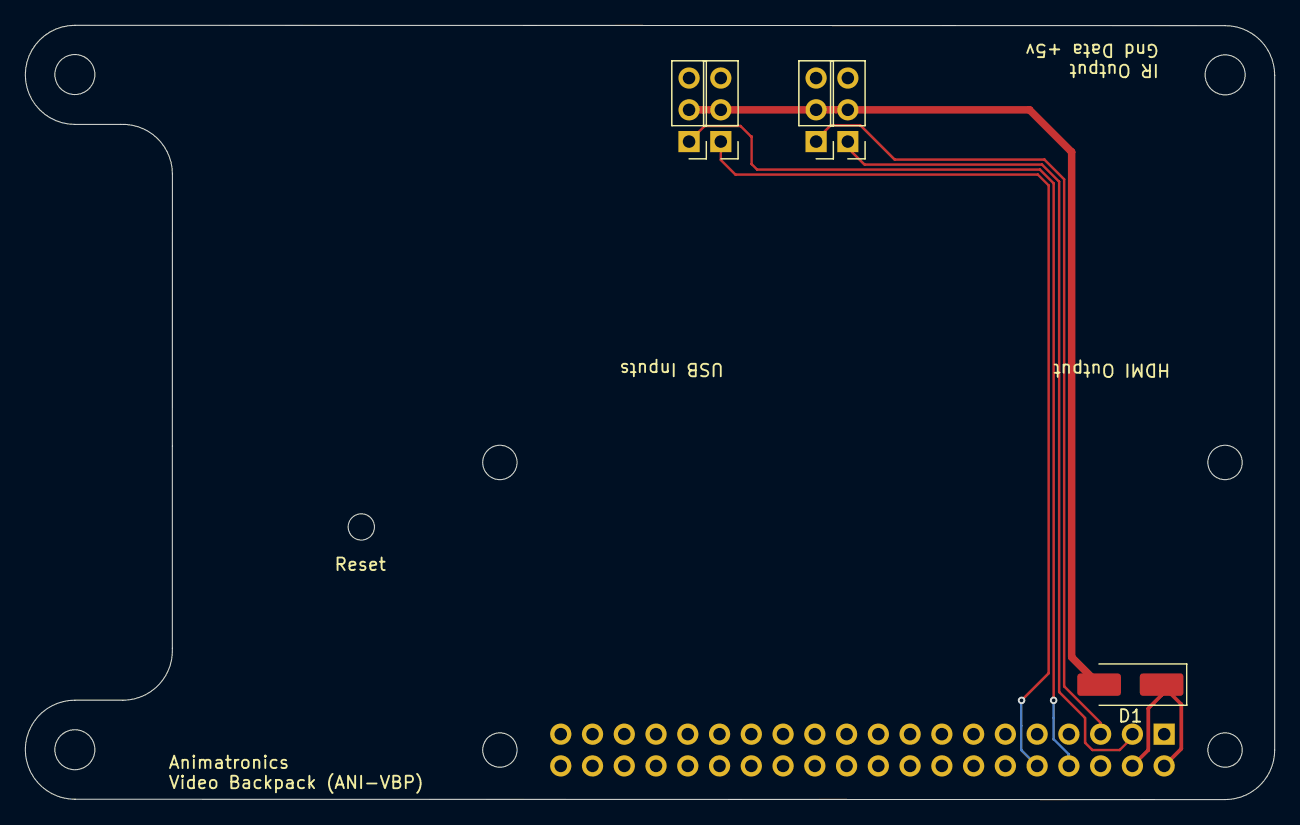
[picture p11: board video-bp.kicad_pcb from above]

Board: 2 copper layers, 99.9 x 61.9 mm, 9 parts (1 on the bottom side), 7 nets.

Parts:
A1: Raspberry_Pi_2_3; Raspberry_Pi_Zero_Socketed_THT_FaceDown_MountingHoles
D1: MBRA340; D_SMA_Handsoldering
H1, H2, H3: MountingHole; MountingHole_3.2mm_M3
J1: GPIO9; PinHeader_1x03_P2.54mm_Vertical
J2: GPIO8; PinHeader_1x03_P2.54mm_Vertical
J3: GPIO5; PinHeader_1x03_P2.54mm_Vertical
J4: GPIO4; PinHeader_1x03_P2.54mm_Vertical

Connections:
+5VA: D1.2 (A), J1.2, J2.2, J3.2, J4.2
+5VP: A1.2 (5V), A1.4 (5V), D1.1 (K)
GND: A1.6 (GND), A1.9 (GND), A1.14 (GND), A1.20 (GND), A1.25 (GND), A1.30 (GND), A1.34 (GND), A1.39 (GND), J1.3, J2.3, J3.3, J4.3
unnamed: A1.8 (GPIO14/TXD), J1.1
unnamed: A1.10 (GPIO15/RXD), J2.1
unnamed: A1.5 (SCL/GPIO3), J3.1
unnamed: A1.3 (SDA/GPIO2), J4.1

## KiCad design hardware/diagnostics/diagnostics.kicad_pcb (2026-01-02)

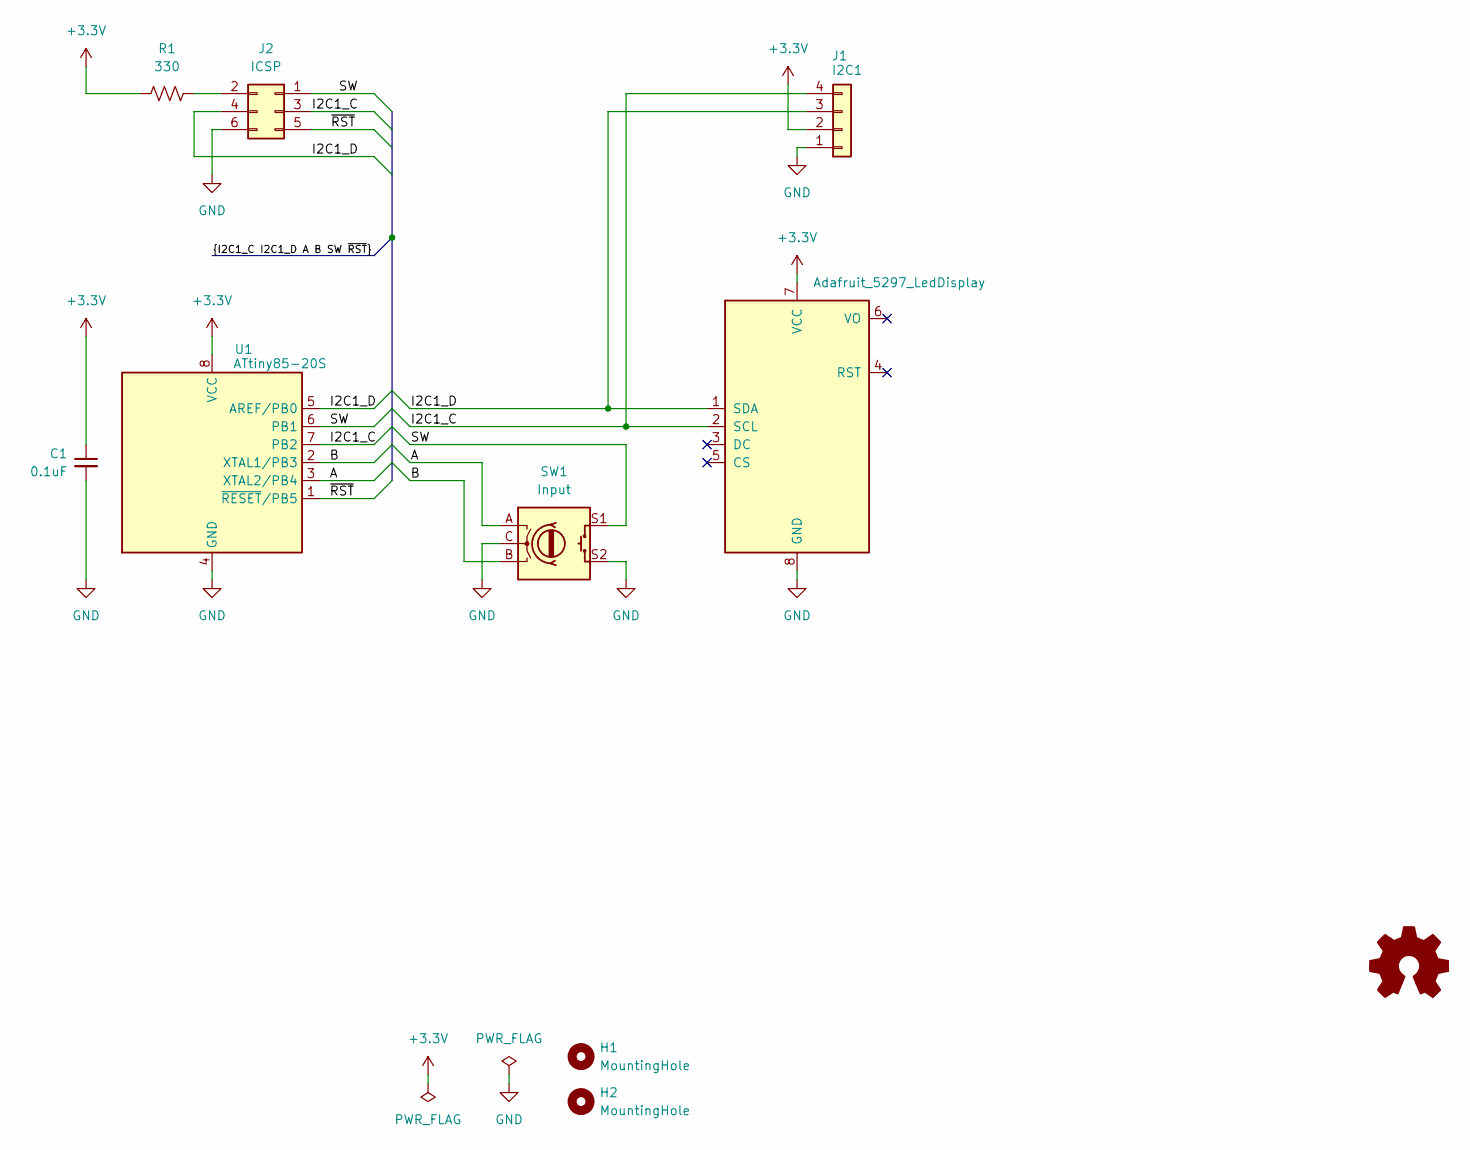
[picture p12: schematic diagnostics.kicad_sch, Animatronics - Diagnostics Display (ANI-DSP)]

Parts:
C1: 0.1uF; C_1206_3216Metric_Pad1.33x1.80mm_HandSolder
DS1: Adafruit_5297_LedDisplay; Adafruit_5297
H1, H2: MountingHole; MountingHole_3.2mm_M3
J1: I2C1; JST_SH_SM04B-SRSS-TB_1x04-1MP_P1.00mm_Horizontal
J2: ICSP; PinHeader_2x03_P2.54mm_Vertical
R1: 330; R_1206_3216Metric_Pad1.30x1.75mm_HandSolder
SW1: Input; RotaryEncoder_Bourns_Vertical_PEC12R-3x17F-Sxxxx
U1: ATtiny85-20S; SOIC-8_5.3x5.3mm_P1.27mm

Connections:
+3.3V: C1.1, DS1.7 (VCC), J1.2, R1.1, U1.8 (VCC)
/A: SW1.A, U1.3 (XTAL2/PB4)
/B: SW1.B, U1.2 (XTAL1/PB3)
/I2C1_C: DS1.2 (SCL), J1.4, J2.3, U1.7 (PB2)
/I2C1_D: DS1.1 (SDA), J1.3, J2.4, U1.5 (AREF/PB0)
/SW: J2.1, SW1.S1, U1.6 (PB1)
/~RST: J2.5, U1.1 (~RESET/PB5)
GND: C1.2, DS1.8 (GND), J1.1, J2.6, SW1.C, SW1.S2, U1.4 (GND)
unnamed: J2.2, R1.2

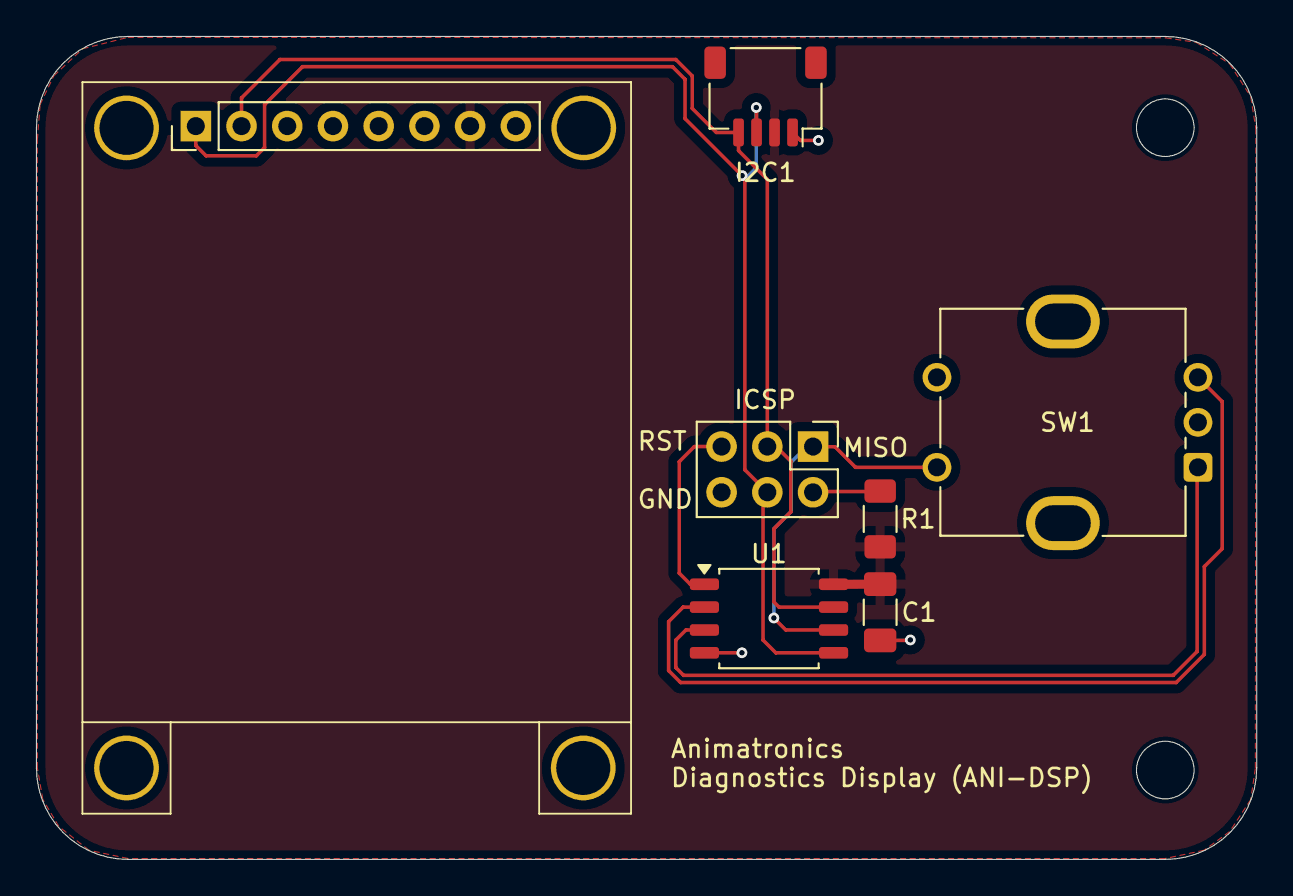
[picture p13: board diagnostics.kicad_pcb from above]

Board: 2 copper layers, 67.8 x 45.7 mm, 9 parts (0 on the bottom side), 9 nets.

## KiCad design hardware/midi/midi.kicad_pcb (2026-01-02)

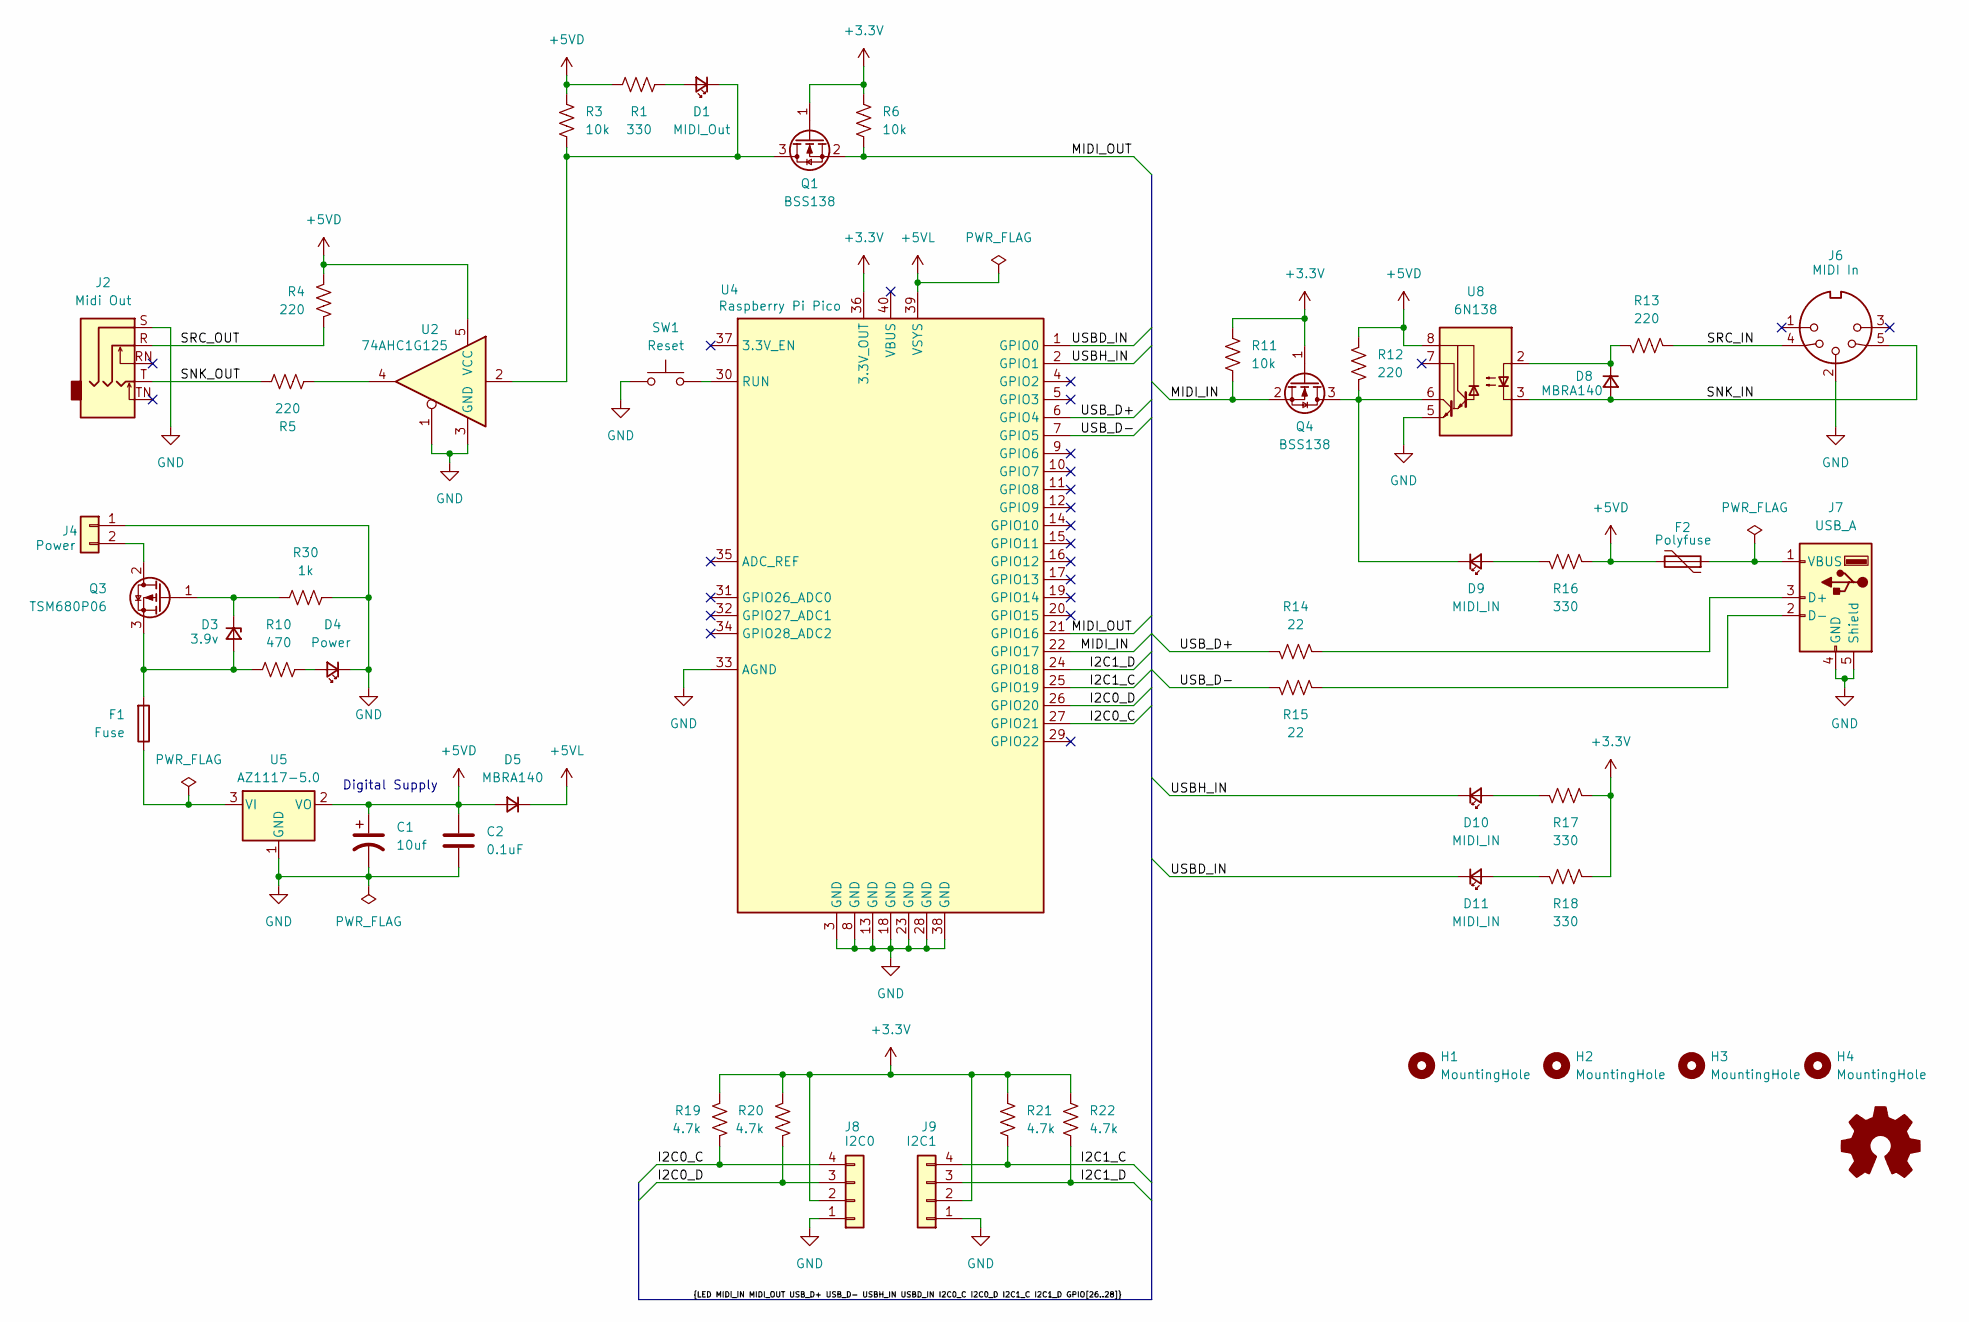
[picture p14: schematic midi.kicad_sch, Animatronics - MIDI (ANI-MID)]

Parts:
C1: 10uf; CP_Radial_D5.0mm_P2.00mm
C2: 0.1uF; C_Rect_L4.0mm_W2.5mm_P2.50mm
D1: MIDI_Out; LED_1206_3216Metric_Pad1.42x1.75mm_HandSolder
D3: 3.9v; D_SOD-123
D4: Power; LED_1206_3216Metric_Pad1.42x1.75mm_HandSolder
D5, D8: MBRA140; D_SMA_Handsoldering
D9, D10, D11: MIDI_IN; LED_1206_3216Metric_Pad1.42x1.75mm_HandSolder
F1: Fuse; atc_fuse_vertical
F2: Polyfuse; Fuse_1206_3216Metric_Pad1.42x1.75mm_HandSolder
H1, H2, H3, H4: MountingHole; MountingHole_3.2mm_M3
J2: Midi Out; Jack_3.5mm_Adafruit_1699_Horizontal
J4: Power; PhoenixContact_MC_1,5_2-G-3.81_1x02_P3.81mm_Horizontal
J6: MIDI In; MIDI_DIN_5
J7: USB_A; USB_A_Molex_67643_Horizontal
J8: I2C0; JST_SH_BM04B-SRSS-TB_1x04-1MP_P1.00mm_Vertical
J9: I2C1; JST_SH_BM04B-SRSS-TB_1x04-1MP_P1.00mm_Vertical
Q1, Q4: BSS138; SOT-23
Q3: TSM680P06; TO-252-2
R1, R16, R17, R18: 330; R_1206_3216Metric_Pad1.30x1.75mm_HandSolder
R3, R6, R11: 10k; R_1206_3216Metric_Pad1.30x1.75mm_HandSolder
R4, R5, R12, R13: 220; R_1206_3216Metric_Pad1.30x1.75mm_HandSolder
R10: 470; R_1206_3216Metric_Pad1.30x1.75mm_HandSolder
R14, R15: 22; R_1206_3216Metric_Pad1.30x1.75mm_HandSolder
R19, R20, R21, R22: 4.7k; R_1206_3216Metric_Pad1.30x1.75mm_HandSolder
R30: 1k; R_1206_3216Metric_Pad1.30x1.75mm_HandSolder
SW1: Reset; SW_PUSH_6mm
U2: 74AHC1G125; SOT-23-5_HandSoldering
U4: Raspberry Pi Pico; DIP-40_W15.24mm
U5: AZ1117-5.0; SOT-223-3_TabPin2
U8: 6N138; SMDIP-8_W9.53mm

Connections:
+3.3V: J8.2, J9.2, Q1.1 (G), Q4.1 (G), R6.2, R11.2, R17.2, R18.2, R19.2, R20.2, R21.2, R22.2, U4.36 (3.3V_OUT)
+5VD: C1.1, C2.1, D5.2 (A), F2.2, R1.2, R3.1, R4.2, R12.1, R16.2, U2.5 (VCC), U5.2 (VO), U8.8 (VCC)
+5VL: D5.1 (K), U4.39 (VSYS)
/I2C0_C: J8.4, R19.1, U4.27 (GPIO21)
/I2C0_D: J8.3, R20.1, U4.26 (GPIO20)
/I2C1_C: J9.4, R21.1, U4.25 (GPIO19)
/I2C1_D: J9.3, R22.1, U4.24 (GPIO18)
/MIDI_IN: Q4.2 (S), R11.1, U4.22 (GPIO17)
/MIDI_OUT: Q1.2 (S), R6.1, U4.21 (GPIO16)
/SNK_IN: D8.2 (A), J6.5, U8.3 (C2)
/SNK_OUT: J2.T, R5.2
/SRC_IN: J6.4, R13.1
/SRC_OUT: J2.R, R4.1
/USBD_IN: D11.1 (K), U4.1 (GPIO0)
/USBH_IN: D10.1 (K), U4.2 (GPIO1)
/USB_D+: R14.2, U4.6 (GPIO4)
/USB_D-: R15.1, U4.7 (GPIO5)
GND: C1.2, C2.2, D4.1 (K), J2.S, J4.1, J6.2, J7.4 (GND), J7.5 (Shield), J8.1, J9.1, R30.2, SW1.1, U2.1, U2.3 (GND), U4.3 (GND), U4.8 (GND), U4.13 (GND), U4.18 (GND), U4.23 (GND), U4.28 (GND), U4.33 (AGND), U4.38 (GND), U5.1 (GND), U8.5 (GND)
unnamed: D1.2 (A), R1.1
unnamed: D1.1 (K), Q1.3 (D), R3.2, U2.2
unnamed: D3.2 (A), F1.2, Q3.3 (S), R10.1
unnamed: D3.1 (K), Q3.1 (G), R30.1
unnamed: D4.2 (A), R10.2
unnamed: D8.1 (K), R13.2, U8.2 (C1)
unnamed: D9.2 (A), R16.1
unnamed: D9.1 (K), Q4.3 (D), R12.2, U8.6 (VO2)
unnamed: D10.2 (A), R17.1
unnamed: D11.2 (A), R18.1
unnamed: J4.2, Q3.2 (D)
unnamed: J7.3 (D+), R14.1
unnamed: J7.2 (D-), R15.2
unnamed: F2.1, J7.1 (VBUS)
unnamed: R5.1, U2.4
unnamed: SW1.2, U4.30 (RUN)
unnamed: F1.1, U5.3 (VI)

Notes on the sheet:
Digital Supply

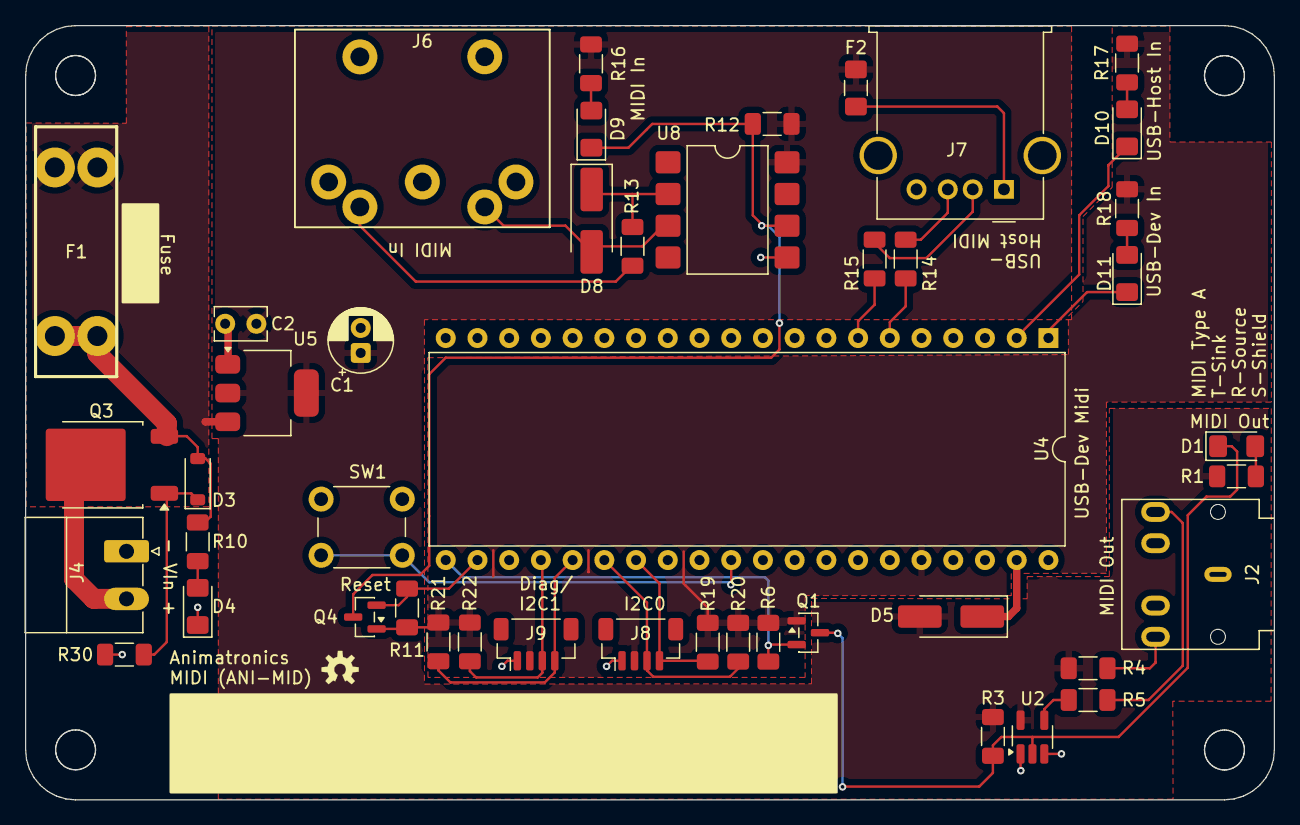
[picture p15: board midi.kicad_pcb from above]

Board: 2 copper layers, 100.0 x 62.0 mm, 49 parts (0 on the bottom side), 35 nets.

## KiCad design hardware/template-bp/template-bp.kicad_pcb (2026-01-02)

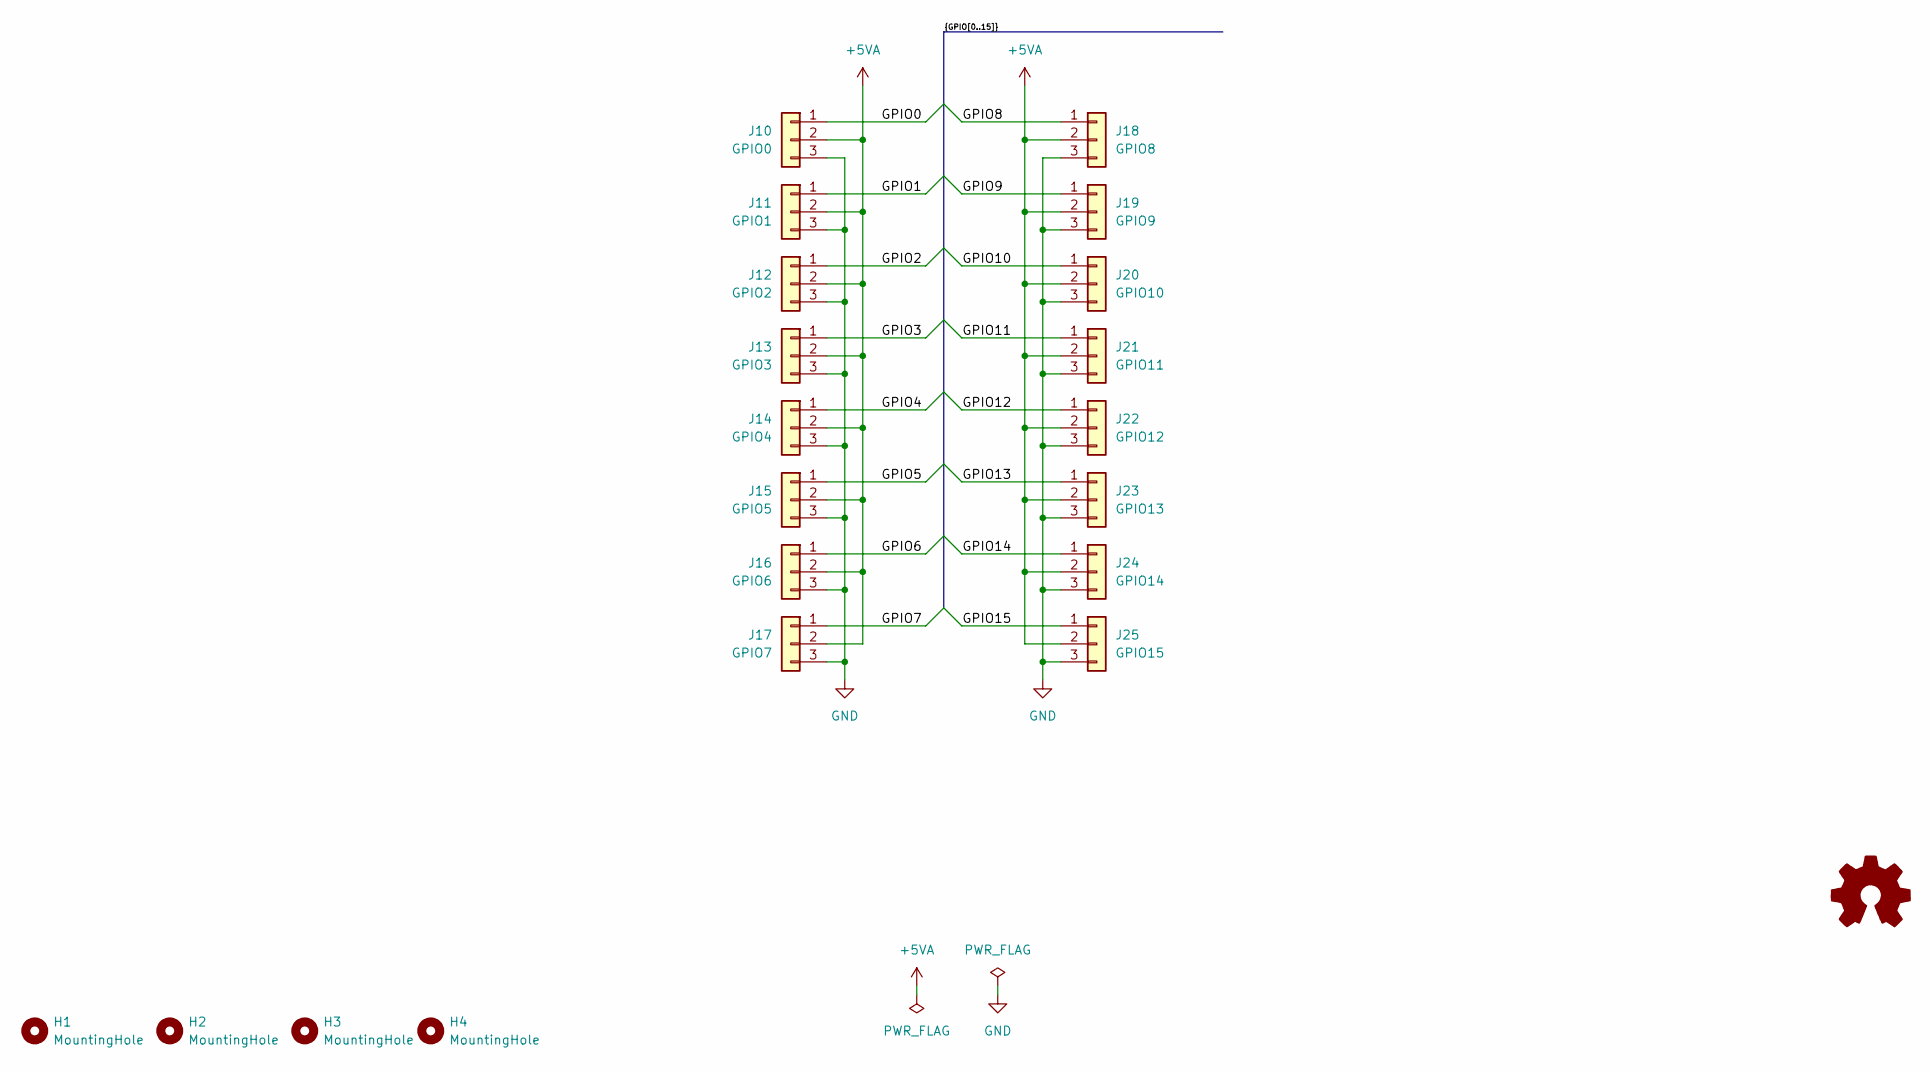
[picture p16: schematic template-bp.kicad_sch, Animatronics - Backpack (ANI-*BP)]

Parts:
H1, H2, H3, H4: MountingHole; MountingHole_3.2mm_M3
J10: GPIO0; PinHeader_1x03_P2.54mm_Vertical
J11: GPIO1; PinHeader_1x03_P2.54mm_Vertical
J12: GPIO2; PinHeader_1x03_P2.54mm_Vertical
J13: GPIO3; PinHeader_1x03_P2.54mm_Vertical
J14: GPIO4; PinHeader_1x03_P2.54mm_Vertical
J15: GPIO5; PinHeader_1x03_P2.54mm_Vertical
J16: GPIO6; PinHeader_1x03_P2.54mm_Vertical
J17: GPIO7; PinHeader_1x03_P2.54mm_Vertical
J18: GPIO8; PinHeader_1x03_P2.54mm_Vertical
J19: GPIO9; PinHeader_1x03_P2.54mm_Vertical
J20: GPIO10; PinHeader_1x03_P2.54mm_Vertical
J21: GPIO11; PinHeader_1x03_P2.54mm_Vertical
J22: GPIO12; PinHeader_1x03_P2.54mm_Vertical
J23: GPIO13; PinHeader_1x03_P2.54mm_Vertical
J24: GPIO14; PinHeader_1x03_P2.54mm_Vertical
J25: GPIO15; PinHeader_1x03_P2.54mm_Vertical

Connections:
+5VA: J10.2, J11.2, J12.2, J13.2, J14.2, J15.2, J16.2, J17.2, J18.2, J19.2, J20.2, J21.2, J22.2, J23.2, J24.2, J25.2
/GPIO0: J10.1
/GPIO1: J11.1
/GPIO2: J12.1
/GPIO3: J13.1
/GPIO4: J14.1
/GPIO5: J15.1
/GPIO6: J16.1
/GPIO7: J17.1
/GPIO8: J18.1
/GPIO9: J19.1
/GPIO10: J20.1
/GPIO11: J21.1
/GPIO12: J22.1
/GPIO13: J23.1
/GPIO14: J24.1
/GPIO15: J25.1
GND: J10.3, J11.3, J12.3, J13.3, J14.3, J15.3, J16.3, J17.3, J18.3, J19.3, J20.3, J21.3, J22.3, J23.3, J24.3, J25.3

Board: 2 copper layers, 20 parts (0 on the bottom side), 2 nets, no tracks yet.

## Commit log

2025-02-15 Hardware Rev 1.0
    [diagnostics.kicad_pcb, diagnostics.kicad_sch, dmx.kicad_pcb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]
2026-01-01 Rev 1.1: - Update to latest KiCad - Fixed short in servo board - Updates to right-angle diag connector on servo boards - Fixed microproc footprint on diag board - Flipped I2C connector to top of diag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
    [diagnostics.kicad_pcb, diagnostics.kicad_sch, dmx.kicad_pcb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]
2026-07-12 Add inventory documentation for DaBones project
    This document provides a comprehensive inventory of hardware, prototypes, and development status for the DaBones project, including completed tasks and future needs for various components.

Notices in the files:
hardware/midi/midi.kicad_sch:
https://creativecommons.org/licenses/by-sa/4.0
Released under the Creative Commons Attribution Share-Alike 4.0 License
